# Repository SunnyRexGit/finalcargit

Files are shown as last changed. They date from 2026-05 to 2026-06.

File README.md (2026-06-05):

# ESP32-S3 遥控小车工程

函数说明和调参入口见：[main.cpp 函数说明与调参指南](docs/main_function_guide.md)。

本项目使用 ESP32-S3 作为主控，通过 MC7RE 2.4G 接收机读取遥控器通道，通过 TTL-RS485 控制 6 个闭环步进电机，通过 PCA9685 控制 4 路舵机。项目替代旧安卓 WiFi TCP 控制方式，主控制方式改为遥控器，不依赖安卓 App，也不依赖 WiFi TCP。

当前固件采用 **M.BUS / SBUS 串行输入**：GPIO18 读取接收机信号，串口参数为 `100000, SERIAL_8E2`，默认启用反相读取。SBUS 原始通道值按 `172~1811` 映射到 `1000~2000`，中位为 `1500`。

## 文件结构

```text
.
├── platformio.ini
├── include/
│   └── config.h
├── src/
│   └── main.cpp
└── README.md
```

## 完整接线表

### ESP32-S3 到 TTL-RS485

| ESP32-S3 | TTL-RS485 |
| --- | --- |
| GPIO16 | RX |
| GPIO17 | TX |
| GND | GND |

串口参数固定为 `115200, SERIAL_8N1`。不要把 RS485 改到其他 GPIO。

### ESP32-S3 到 PCA9685

| ESP32-S3 | PCA9685 |
| --- | --- |
| GPIO11 | SDA |
| GPIO12 | SCL |
| 3.3V/5V  | VCC |
| GND | GND |

PCA9685 地址为 `0x40`，PWM 频率为 `50Hz`。不要改成 GPIO21/GPIO22。

### PCA9685 到舵机

| PCA9685 通道 | 逻辑编号 | 功能 |
| --- | --- | --- |
| 0 | S1 | 云台 / 机械臂旋转 |
| 1 | S2 | 夹爪一侧 |
| 2 | S3 | 夹爪另一侧 |
| 3 | S4 | 机械臂前后 |

### RS485 电机编号

| 地址 | 功能 |
| ---- | --- |
| 1 | M1 底盘轮 1 |
| 2 | M2 底盘轮 2 |
| 3 | M3 底盘轮 3 |
| 4 | M4 底盘轮 4 |
| 5 | M5 机械臂升降 |
| 6 | M6 物料盘旋转 |

M1~M4 使用速度模式，M5/M6 使用绝对位置模式。

### MC7RE 到 ESP32-S3

| MC7RE | ESP32-S3 |
| --- | --- |
| M.BUS / SBUS Signal | GPIO18 |
| VCC | 按接收机规格接 5V 或 3.3V |
| GND | GND |

所有模块必须共地。接收机如果输出的不是反相 SBUS，可在 `include/config.h` 中把 `RC_SERIAL_INVERTED` 改为 `0`。

### 激光模块

| 激光模块 | ESP32-S3 |
| --- | --- |
| Signal | GPIO15 |
| VCC | 按模块规格供电 |
| GND | GND |

GPIO15 默认输出高电平，激光常亮；进入 B2 自动工位模式时按 `LASER_BLINK_INTERVAL_MS` 间隔闪烁。

## 遥控器通道说明

| 通道 | 默认索引宏 | 遥控器操作 | 作用 |
| ---- | --- | --- | --- |
| CH1  | `RC_CH1_INDEX 0` | 右摇杆左右 | 底盘横移 / S1 云台 / 自动工位选择 |
| CH2  | `RC_CH2_INDEX 1` | 右摇杆上下 | 底盘前后 / S4 前后 / 自动工位选择 |
| CH3  | `RC_CH3_INDEX 2` | 左摇杆上下 | M5 机械臂升降 |
| CH4  | `RC_CH4_INDEX 3` | 左摇杆左右 | 底盘原地转向 / 夹爪 |
| CH5  | `RC_CH5_INDEX 4` | 两段开关 | 大模式切换 |
| CH6  | `RC_CH6_INDEX 5` | 两段开关或旋钮 | 子模式切换 |

如果实测通道不对应，修改 `include/config.h` 里的 `RC_CHx_INDEX` 宏即可。例如 CH1 和 CH2 反了，就交换 `RC_CH1_INDEX` 与 `RC_CH2_INDEX`。

模式划分：

```text
CH5 < 1500：底盘 / 物料盘模式
CH5 > 1500：机械臂模式

CH6 < 1500：普通子模式
CH6 > 1500：特殊子模式
```

### A1 普通底盘模式

触发条件：`CH5 < 1500 && CH6 < 1500`

| 通道 | 功能 |
| ---- | --- |
| CH1  | 底盘左右横移 `vx` |
| CH2  | 底盘前后移动 `vy` |
| CH4  | 原地转向 `w` |
| CH3  | 为安全默认不参与  |

混控公式：

```cpp
m1 = vy - vx + w;
m2 = -vy + vx + w;
m3 = -vy - vx + w;
m4 = vy + vx + w;
```

固件会把四路输出归一化到 `-100~100`，再映射到 `0~250 RPM`。

底盘速度是线性映射：遥控器返回值离中位越远，速度百分比越大；速度百分比再线性换算成 `0~MAX_SPEED_RPM`。加速度仍由 `ACCEL_WHEEL` 固定控制，不随摇杆变化。

### A2 物料盘模式

触发条件：`CH5 < 1500 && CH6 > 1500`。进入该模式后底盘会停止。

| 遥控器操作 | 功能 |
| --- | --- |
| CH1 左打到底  | M6 左转一步，`motor6Pos -= 900` |
| CH1 右打到底  | M6 右转一步，`motor6Pos += 900` |
| CH2 下拉到底  | M6 回中，`motor6Pos = 1800` |

这些动作都是边沿触发：摇杆打到底只触发一次，必须回中后才能再次触发。

### B1 底盘微调模式

触发条件：`CH5 > 1500 && CH6 < 1500`。该模式用于底盘低速微调，操控方式和普通底盘模式一致，但满摇杆速度被限制到 `FINE_WHEEL_CMD_MAX`。

| 通道 | 功能 |
| ---- | ---- |
| CH1  | 底盘左右横移，低速微调 |
| CH2  | 底盘前后移动，低速微调 |
| CH4  | 底盘原地转向，低速微调 |

B1 不再控制 S1/S4/M5 或夹爪；机械臂动作由 B2 自动工位流程负责。

### B2 自动工位模式

触发条件：`CH5 > 1500 && CH6 > 1500`。进入该模式后底盘停止，手动机械臂控制暂停，M5 不被 CH3 抢控制。

| 遥控器操作 | 自动动作 |
| --- | --- |
| CH1 左打到底  | 去预夹位 State 1 |
| CH2 上推到底  | 去转台位 State 2 |
| CH1 右打到底  | 去预放位 State 3 |
| CH2 下拉到底  | 取消当前自动动作 / 急停 |

自动工位使用 `millis()` 非阻塞状态机。动作运行中不会接受新的工位指令，除非 CH2 下拉到底取消。

## 控制参数说明

主要参数集中在 `include/config.h`：

| 参数 | 当前值 / 含义 |
| ---- | --- |
| `WHEEL_CMD_MAX` | `100`，底盘上层速度范围为 `-100~100` |
| `FINE_WHEEL_CMD_MAX` | `15`，B1 底盘微调模式满摇杆最大速度命令 |
| `MAX_SPEED_RPM` | `250`，轮电机最大转速映射 |
| `MIN_EFFECTIVE_CMD` | `5`，小于该值视为 0 |
| `RC_DEADZONE` | `60`，遥控器摇杆死区 |
| `RC_TIMEOUT_MS` | `300`，超过该时间无有效帧触发失控保护 |
| `M5_PULSE_MIN/MAX` | M5 机械臂升降最小/最大目标脉冲数 |
| `M5_STEP` | `400`，M5 每次连续更新增加或减少的脉冲数 |
| `M6_STEP` | `900`，M6 每次转动增加或减少的脉冲数 |
| `M6_CENTER` | `1800`，M6 回中目标脉冲数 |
| `S1` | 范围 `0~180` |
| `GRIPPER_OPEN_ANGLE` | `90`，夹爪状态为 1 时写入 |
| `GRIPPER_CLOSE_ANGLE` | `150`，夹爪状态为 0 时写入 |
| `S4` | 实际角度范围 `0~180`，代码直接写入该角度 |
| `HIGH_POS` | `500`，所有 S1/S4 旋转前都会先回到该安全高位，低于 1000 脉冲 |
| 预夹位 | 详见 `auto_station/README.md` |
| 转台位 | 详见 `auto_station/README.md` |
| 预放位 | 详见 `auto_station/README.md` |
| `POSITION_SPEED_M5_AUTO` | `800`，B2 自动工位中 M5 的速度参数 |
| `AUTO_M5_MOVE_WAIT_MS` | `4000`，自动工位每次 M5 位置命令后的等待时间 |

方向反了优先改这些宏：

```cpp
#define CHASSIS_X_SIGN 1
#define CHASSIS_Y_SIGN 1
#define CHASSIS_W_SIGN 1
#define M1_SIGN 1
#define M2_SIGN 1
#define M3_SIGN 1
#define M4_SIGN 1
#define M5_DIR_SIGN 1
#define GRIPPER_S3_REVERSED 0
```

## 完整调试流程

### 第 0 步：安全准备

1. 小车架空，四个轮子离地。
2. 机械臂不要装重物。
3. 初次测试时舵机不要带负载。
4. 确认所有 GND 共地。
5. 确认 RS485 A/B 接线。
6. 确认 PCA9685 单独供电能力足够。
7. 打开 PlatformIO 串口监视器，波特率 `115200`。
8. 准备随时断电。

### 第 1 步：编译上传

```bash
pio run
pio run -t upload
pio device monitor -b 115200
```

默认环境是 `esp32-s3-devkitc-1`。如果你的开发板不是这个型号，修改 `platformio.ini` 中的 `board`。

### 第 2 步：遥控器通道测试

先只给 ESP32 和接收机供电，不接电机负载。串口会周期打印：

```text
CH1=...
CH2=...
CH3=...
CH4=...
CH5=...
CH6=...
mode=...
failsafe=...
```

逐个推动摇杆和开关，确认：

```text
CH1：右摇杆左右
CH2：右摇杆上下
CH3：左摇杆上下
CH4：左摇杆左右
CH5：模式开关
CH6：子模式开关
```

如果通道不对，修改 `RC_CHx_INDEX`。如果方向反了，先不要动接线，优先修改方向宏。

### 第 3 步：失控保护测试

1. 打开遥控器，确认通道正常。
2. 关闭遥控器。
3. 串口应该显示 `FAILSAFE TRIGGERED`。
4. M1~M6 应停止，自动工位应取消。
5. 重新打开遥控器。
6. 必须所有摇杆回中后，串口显示 `FAILSAFE CLEARED`，然后才恢复控制。

失控急停命令只在刚进入失控时发送一次，避免 RS485 总线被重复急停命令占满。

### 第 4 步：PCA9685 和舵机测试

1. 只接 PCA9685 和舵机。
2. 不装机械臂负载。
3. CH5 进入机械臂模式，CH6 进入手动模式。
4. 用 CH1 测试 S1。
5. 用 CH4 左/右打到底测试 S2/S3 夹爪状态变量，确认左打到底为闭合 `0`，右打到底为张开 `1`。
6. 用 CH2 测试 S4。
7. 如果 S4 方向反，直接调整 `include/config.h` 中对应的 S4 实际角度，或检查机械安装。
8. 如果夹爪堵转，修改 `GRIPPER_OPEN_ANGLE` / `GRIPPER_CLOSE_ANGLE`。如果 S3 方向相反，改 `GRIPPER_S3_REVERSED`。

### 第 5 步：RS485 单电机测试

1. 先只接一个底盘电机。
2. 测试 M1 正反转。
3. 再测试 M2/M3/M4。
4. 确认地址是否分别是 1/2/3/4。
5. 如果不动，检查电机地址、RS485 A/B、供电、GND。

### 第 6 步：底盘架空测试

1. 四个轮子离地。
2. CH5 进入底盘模式。
3. CH6 进入普通底盘子模式。
4. 测试前后。
5. 测试左右横移。
6. 测试原地转向。
7. 如果整体方向反，修改 `CHASSIS_X_SIGN` / `CHASSIS_Y_SIGN` / `CHASSIS_W_SIGN`。
8. 如果只有一个轮子方向反，修改对应的 `Mx_SIGN`。

### 第 7 步：M5 升降测试

1. 机械臂不要带重物。
2. CH5 进入机械臂模式。
3. CH6 进入手动模式。
4. CH3 上推，M5 应该上升，`motor5Pos` 减小。
5. CH3 下拉，M5 应该下降，`motor5Pos` 增大。
6. 确认 `M5_PULSE_MIN~M5_PULSE_MAX` 脉冲限位生效。
7. 如果方向反，修改 `M5_DIR_SIGN`。

### 第 8 步：M6 物料盘测试

1. CH5 进入底盘模式。
2. CH6 进入物料盘模式。
3. CH1 左打到底，M6 左转一步 `900`。
4. CH1 右打到底，M6 右转一步 `900`。
5. CH2 下拉到底，M6 回中到 `1800`。
6. 确认必须摇杆回中后才能再次触发。

### 第 9 步：机械臂手动测试

1. CH5 进入机械臂模式。
2. CH6 进入手动模式。
3. CH1 控制底盘左右横移，速度应明显低于普通底盘模式。
4. CH2 控制底盘前后移动，速度应明显低于普通底盘模式。
5. CH4 控制底盘原地转向，速度应明显低于普通底盘模式。

### 第 10 步：自动工位测试

1. CH5 进入机械臂模式。
2. CH6 进入自动工位模式。
3. CH1 左打到底 -> 预夹位。
4. CH2 上推到底 -> 转台位。
5. CH1 右打到底 -> 预放位。
6. CH2 下拉到底 -> 取消 / 急停。
7. 观察串口是否按 `AUTO_STEP` 顺序执行。

自动工位现在所有切换都会先让 M5 回到 `HIGH_POS = 500`，等待 `AUTO_M5_MOVE_WAIT_MS`，再旋转 S1/S4，最后移动 M5 到目标位置，避免机械臂主轴旋转时碰撞。如果 B2 反应慢，优先调小 `AUTO_M5_MOVE_WAIT_MS`；如果旋转前 M5 还没完全回高位，就调大它。

夹爪在自动工位中的状态规则：去预夹位 State 1 时，M5 回到 `HIGH_POS` 后夹爪状态设为 `1=张开`；去转台位 State 2 或预放位 State 3 时，自动动作一启动就先把夹爪状态设为 `0=闭合`，再抬升 M5。

### 第 11 步：完整作业流程测试

1. 底盘移动到目标物附近。
2. 进入预夹位。
3. 使用 B1 底盘微调模式对准夹取位置。
4. 夹爪闭合。
5. 转到转台位。
6. M6 物料盘旋转。
7. 底盘移动到放置区。
8. 进入预放位。
9. 夹爪打开。

## 常见问题排查

### 1. 遥控器通道没有变化怎么办

检查接收机是否输出 SBUS/M.BUS，信号线是否接到 GPIO18，遥控器和接收机是否已对频。确认 `RC_SERIAL_INVERTED` 是否符合接收机输出。

### 2. SBUS / M.BUS 没有数据怎么办

先只接 ESP32 和接收机，打开串口监视器。如果始终 failsafe，尝试把 `RC_SERIAL_INVERTED` 改为 `0`，或者确认接收机输出协议不是 PWM 单通道。

### 3. 舵机乱甩怎么办

检查 PCA9685 电源是否独立且电流足够，GND 是否共地。首次测试不要带机械负载，并缩小舵机角度范围。

### 4. S4 方向反了怎么办

S4 现在直接使用实际角度，不再做 `180 - angle` 换算。如果方向不符合预期，检查连杆安装方向，或直接调整自动工位中的 S4 实际角度参数。

### 5. 夹爪堵转怎么办

减小 `GRIPPER_CLOSE_ANGLE` 或增大 `GRIPPER_OPEN_ANGLE` 的安全余量。如果 S3 与 S2 应该反向运动，把 `GRIPPER_S3_REVERSED` 改为 `1`。

### 6. M5 一上电乱跑怎么办

确认 M5 没有在 `setup()` 中清零。本项目只给 M1~M4 清零，M5/M6 保持原有位置记忆。检查驱动器地址、绝对位置模式和机械限位。

### 7. M5 升降方向反了怎么办

修改 `M5_DIR_SIGN`。当前 `motor5Pos` 直接表示 M5 目标脉冲数：CH3 上推时 `motor5Pos -= M5_STEP`，CH3 下拉时 `motor5Pos += M5_STEP`。

### 8. 底盘前后左右方向反了怎么办

修改 `CHASSIS_X_SIGN`、`CHASSIS_Y_SIGN` 或 `CHASSIS_W_SIGN`。如果只是某个轮反了，改对应的 `M1_SIGN` 到 `M4_SIGN`。

### 9. 四个轮子有一个方向不对怎么办

确认电机地址是否正确。如果地址正确，修改对应轮子的 `Mx_SIGN`。

### 10. RS485 电机没响应怎么办

检查电机地址、TTL-RS485 模块供电、A/B 接线、GND 共地、串口波特率。串口会打印电机返回值：`0x02` 表示 OK，`0xE2` 表示参数错误，`0xEE` 表示格式错误。

### 11. 关闭遥控器后电机还在动怎么办

确认接收机在失控时是否输出 SBUS lost frame / failsafe 标志。即使没有标志，固件也会在 `RC_TIMEOUT_MS = 300` 毫秒无有效帧后触发急停。

### 12. PlatformIO 编译库找不到怎么办

检查网络和 PlatformIO 库安装。依赖写在 `platformio.ini`：

```ini
lib_deps =
    adafruit/Adafruit PWM Servo Driver Library
```

### 13. PCA9685 检测不到怎么办

检查 SDA=GPIO11、SCL=GPIO12、地址 `0x40`、VCC、GND。PCA9685 舵机电源和逻辑电源要按模块说明连接，且所有模块共地。

## 继承关系总结

继承自旧 ESP32Robot.ino：

```text
RS485 GPIO16/GPIO17
RS485 115200 SERIAL_8N1
PCA9685 GPIO11/GPIO12
PCA9685 地址 0x40，频率 50Hz
SERVOMIN = 102，SERVOMAX = 512
M1~M6 地址 = 1~6
S1~S4 通道 = 0~3
电机使能、停止、清零、速度、绝对位置命令格式
只给 M1~M4 清零，M5/M6 不清零
```

继承自旧安卓端：

```text
底盘混控逻辑
S1 初始 180，步长 5
S2/S3 打开 90，闭合 150
S4 直接按实际角度写入
M5 现已改为直接脉冲控制，步长 M5_STEP
M6 现已改为直接脉冲控制，步长 M6_STEP，回中 M6_CENTER
HIGH_POS = 500
预夹位、转台位、预放位参数和切换顺序
```

需要实机微调的地方：

```text
SBUS 是否需要反相
RC_CHx_INDEX 通道顺序
底盘方向宏和单轮方向宏
M5_DIR_SIGN
夹爪开合角度和 GRIPPER_S3_REVERSED
自动工位 M5/S1/S4 目标位置
PCA9685 舵机脉宽 SERVOMIN/SERVOMAX
```

第一次上电前必须检查：

```text
小车架空
机械臂无重物
舵机无负载或负载已释放
所有 GND 共地
RS485 A/B、RX/TX 接线正确
PCA9685 供电足够
遥控器可触发 failsafe
随时可以断电
```

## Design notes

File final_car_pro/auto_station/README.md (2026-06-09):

# 自动工位流程梳理

本文按当前代码记录 B2 自动工位流程。所有 S4 角度均为实际写入角度，不再使用逻辑角度换算。

## 自动工位触发

| 遥控动作 | 自动流程 |
| --- | --- |
| CH1 左打到底 | State 1，新预夹位 |
| CH2 上推到底 | State 2，转台连贯宏 |
| CH1 右打到底 | State 3，合并预放宏 |
| CH3 上推超过 `1950` | M5 直接归顶到 `0` |

## 位置目标

| 位置 | M5 脉冲 | S1 实际角度 | S4 实际角度 |
| ---- | --- | --- | --- |
| 新预夹位 | `119860` | `0` | `80` |
| 夹取位 | `139860` | 保持当前 | 保持当前 |
| 转台位 | `76590` | `180` | `170` |
| 转盘预夹位 | `42000` | `180` | `170` |
| 预放位 | `157000` | `0` | `60` |
| M5 顶部 | `0` | 保持当前 | 保持当前 |
| 安全高位 | `500` | 保持当前 | 保持当前 |

## State 1：CH1 左打到底，新预夹位

1. M5 到安全高位 `500`，等待 `3000ms`。
2. S1 到 `0`，S4 到 `80`。
3. 等待 `500ms`。
4. M5 到新预夹位 `119860`，等待 `3000ms`。
5. 完成，当前状态记为 State 1。

## State 2：CH2 上推到底，转台连贯宏

1. M5 到夹取位 `139860`，等待 `2000ms`。
2. 等待 `500ms`。
3. 快速闭合夹爪，S2/S3 直接写 `170`。
4. M5 到安全高位 `500`，等待 `3000ms`。
5. S1 到 `180`，S4 到转台内收角 `170`。
6. 等待 `500ms`。
7. M5 到转台位 `76590`，等待 `2000ms`。
8. 夹爪先半开到 `120`。
9. M5 到顶部 `0`，等待 `3000ms`。
10. 夹爪完全张开到 `60`。
11. M6 转盘步进一次：`motor6Pos + M6_STEP`。
12. 等待 `500ms`。
13. S1 到 `0`，S4 到预放外展角 `60`。
14. 等待 `500ms`。
15. M5 到新预夹位 `119860`，等待 `3000ms`。
16. 完成，当前状态记为 State 1。

## State 3：CH1 右打到底，合并预放宏

1. M5 到顶部 `0`，等待 `3000ms`。
2. 快速确认夹爪张开，S2/S3 直接写 `60`。
3. S4 内收到转盘角 `170`。
4. 等待 `200ms`。
5. S1 到转盘角 `180`。
6. 等待 `1000ms`。
7. M5 去转盘预夹位 `42000`。
8. 等待 `1500ms` 后提前启动夹爪闭合。
9. 快速闭合夹爪，S2/S3 直接写 `170`。
10. 闭合完成后额外等待 `1000ms`。
11. M5 到顶部 `0`，等待 `3000ms`。
12. S1 到预放角 `0`。
13. 等待 `500ms`。
14. M6 转盘反向步进一次：`motor6Pos - M6_STEP`。
15. 等待 `500ms`。
16. S4 外展到预放角 `60`。
17. 等待 `500ms`。
18. M5 到预放位 `157000`，等待 `3000ms`。
19. 完成，当前状态记为 State 3，夹爪保持当前状态。

## 夹爪模式

| 模式 | 行为 |
| ---- | ---- |
| 快速打开 | 直接写 `60` |
| 转台半开 | 直接写 `120` |
| 快速闭合 | 直接写 `170` |

自动流程中，夹爪动作都直接写目标角度，不再分步执行。

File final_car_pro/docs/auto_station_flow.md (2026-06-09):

# 自动工位流程梳理

本文按当前代码记录 B2 自动工位流程。所有 S4 角度均为实际写入角度，不再使用逻辑角度换算。

## 基本角度和等待

| 项目 | 当前值 |
| ---- | --- |
| S4 上电默认实际角度 | `180` |
| S4 实际角度范围 | `0~180` |
| S1 转盘位角度 | `180` |
| S1 预夹/预放角度 | `0` |
| S4 转盘内收角度 | `170` |
| S4 预放外展角度 | `60` |
| 夹爪张开角度 | `60` |
| 夹爪转台半开角度 | `120` |
| 夹爪闭合角度 | `170` |
| 舵机稳定等待 | `500ms` |
| M5 固定到位等待 | `3000ms` |
| State 2 夹取/转台位等待 | `2000ms` |

## 自动工位触发

| 遥控动作 | 自动流程 |
| --- | --- |
| CH1 左打到底 | State 1，新预夹位 |
| CH2 上推到底 | State 2，转台连贯宏 |
| CH1 右打到底 | State 3，合并预放宏 |
| CH3 上推超过 `1950` | M5 直接归顶到 `0` |

## 位置目标

| 位置 | M5 脉冲 | S1 实际角度 | S4 实际角度 |
| ---- | --- | --- | --- |
| 新预夹位 | `119860` | `0` | `80` |
| 夹取位 | `139860` | 保持当前 | 保持当前 |
| 转台位 | `76590` | `180` | `170` |
| 转盘预夹位 | `42000` | `180` | `170` |
| 预放位 | `157000` | `0` | `60` |
| M5 顶部 | `0` | 保持当前 | 保持当前 |
| 安全高位 | `500` | 保持当前 | 保持当前 |

## State 1：CH1 左打到底，新预夹位

1. M5 到安全高位 `500`，等待 `3000ms`。
2. S1 到 `0`，S4 到 `80`。
3. 等待 `500ms`。
4. M5 到新预夹位 `119860`，等待 `3000ms`。
5. 完成，当前状态记为 State 1。

## State 2：CH2 上推到底，转台连贯宏

1. M5 到夹取位 `139860`，等待 `2000ms`。
2. 等待 `500ms`。
3. 快速闭合夹爪，S2/S3 直接写 `170`。
4. M5 到安全高位 `500`，等待 `3000ms`。
5. S1 到 `180`，S4 到转台内收角 `170`。
6. 等待 `500ms`。
7. M5 到转台位 `76590`，等待 `2000ms`。
8. 夹爪先半开到 `120`。
9. M5 到顶部 `0`，等待 `3000ms`。
10. 夹爪完全张开到 `60`。
11. M6 转盘步进一次：`motor6Pos + M6_STEP`。
12. 等待 `500ms`。
13. S1 到 `0`，S4 到预放外展角 `60`。
14. 等待 `500ms`。
15. M5 到新预夹位 `119860`，等待 `3000ms`。
16. 完成，当前状态记为 State 1。

## State 3：CH1 右打到底，合并预放宏

1. M5 到顶部 `0`，等待 `3000ms`。
2. 快速确认夹爪张开，S2/S3 直接写 `60`。
3. S4 内收到转盘角 `170`。
4. 等待 `200ms`。
5. S1 到转盘角 `180`。
6. 等待 `1000ms`。
7. M5 去转盘预夹位 `42000`。
8. 等待 `1500ms` 后提前启动夹爪闭合。
9. 快速闭合夹爪，S2/S3 直接写 `170`。
10. 闭合完成后额外等待 `1000ms`。
11. M5 到顶部 `0`，等待 `3000ms`。
12. S1 到预放角 `0`。
13. 等待 `500ms`。
14. M6 转盘反向步进一次：`motor6Pos - M6_STEP`。
15. 等待 `500ms`。
16. S4 外展到预放角 `60`。
17. 等待 `500ms`。
18. M5 到预放位 `157000`，等待 `3000ms`。
19. 完成，当前状态记为 State 3，夹爪保持当前状态。

## 夹爪模式

| 模式 | 行为 |
| ---- | ---- |
| 快速打开 | 直接写 `60` |
| 转台半开 | 直接写 `120` |
| 快速闭合 | 直接写 `170` |

自动流程中，夹爪动作都直接写目标角度，不再分步执行。

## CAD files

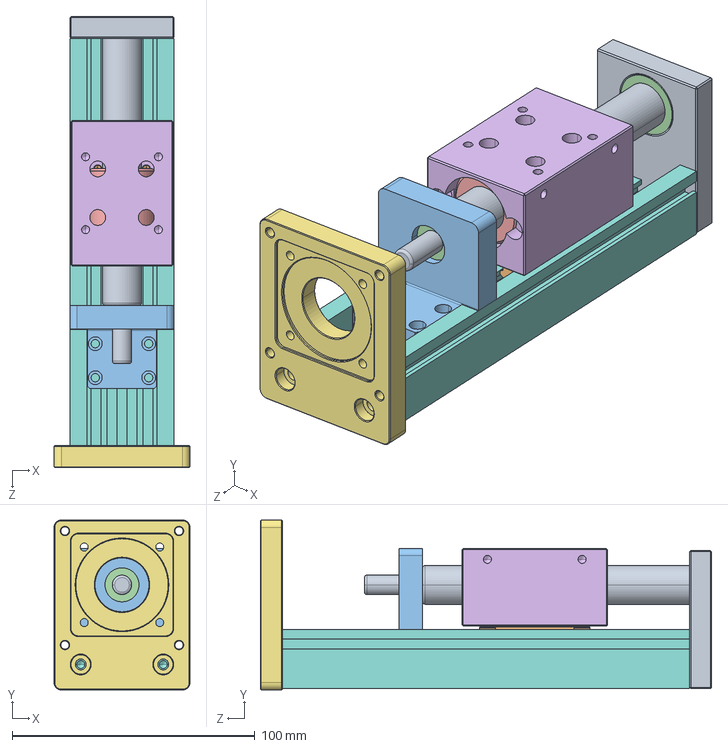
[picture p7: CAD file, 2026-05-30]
final_car_pro/model/标准件/42-57单线..图纸/SGX标准图纸/SGX支撑-50行程.STEP
56.0 x 70.0 x 185.8 mm

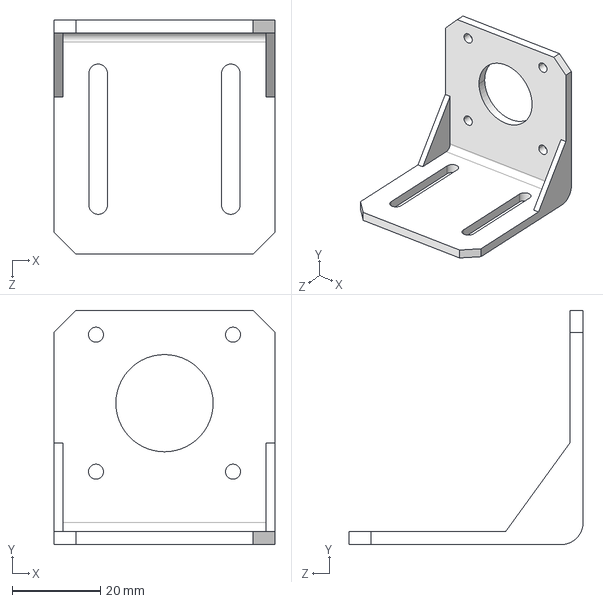
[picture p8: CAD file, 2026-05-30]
final_car_pro/model/标准件/42/42步进电机支架.STEP
50.0 x 53.0 x 53.0 mm

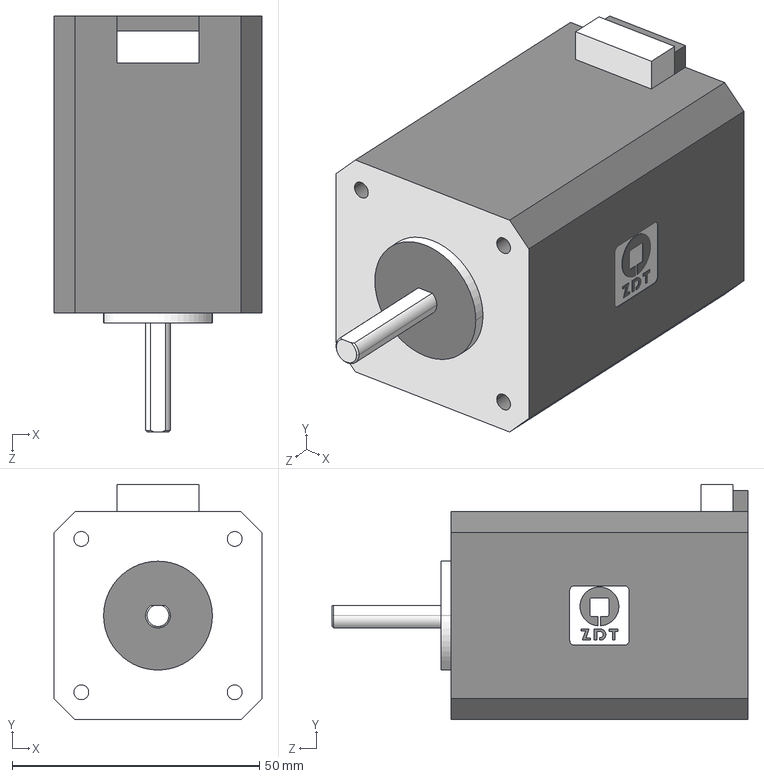
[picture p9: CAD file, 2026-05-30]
final_car_pro/model/标准件/42/单电机/ZDT_STEPPER_MOTOR_42_L60.STEP
42.0 x 47.5 x 84.0 mm

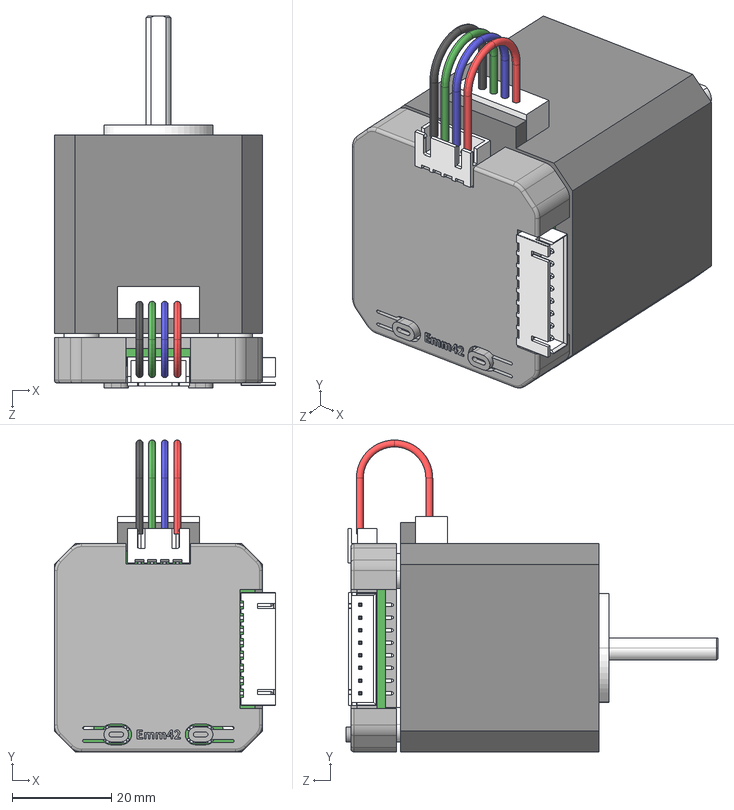
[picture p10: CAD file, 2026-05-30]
final_car_pro/model/标准件/42/电机及驱动外壳/ZDT_X42_L40Motor.STEP
44.7 x 62.9 x 75.0 mm
42_STEPPER_MOTOR
SHIM_3x7x3 x 4
ts-1145a-b-a_White.step x 2
User_Library-XH2_54-4P-AW.step
XH2.54-8P_H-0.step
Extruded.step
Extruded-1.step
M3x6mm_Phillips x 4
ZDT_X42_V1.2
WIRE_2.54

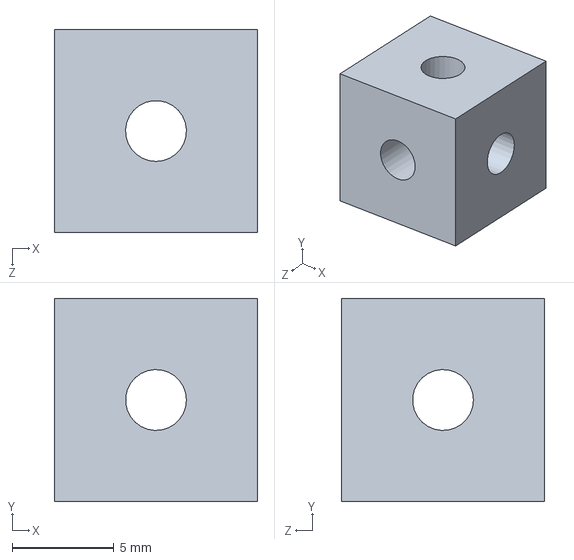
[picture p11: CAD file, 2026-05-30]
final_car_pro/model/标准件/六面螺母.SLDPRT
10.0 x 10.0 x 10.0 mm

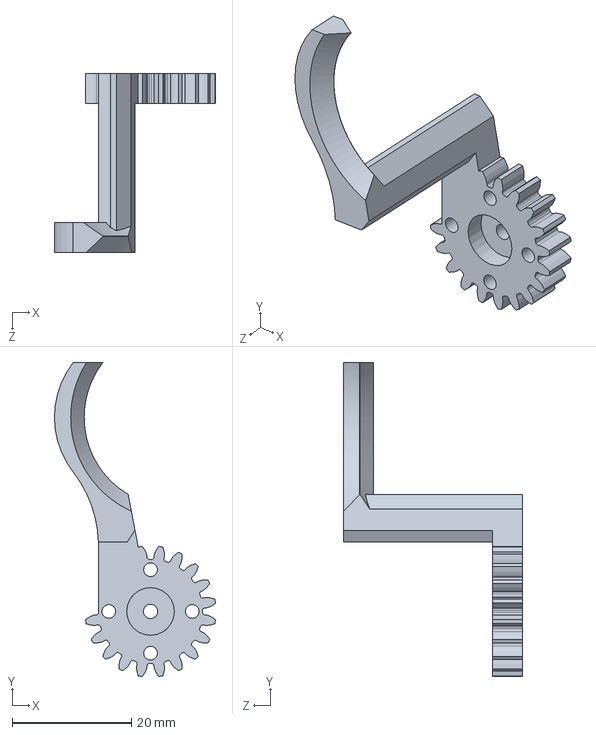
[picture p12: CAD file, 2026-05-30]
final_car_pro/model/零件/夹爪（被动端）.SLDPRT
27.0 x 52.7 x 30.0 mm

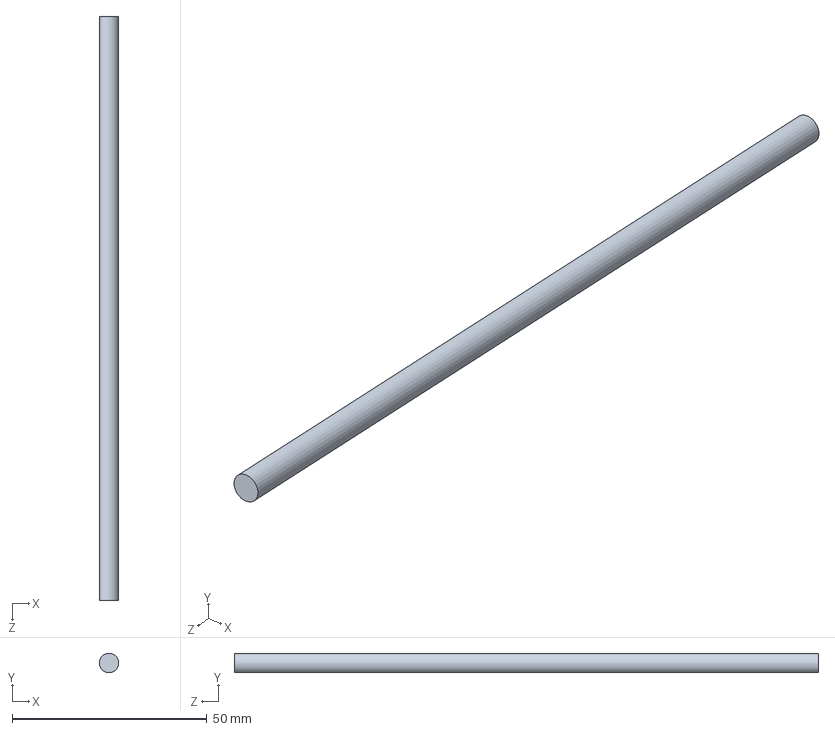
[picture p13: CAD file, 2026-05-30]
final_car_pro/model/标准件/150mm5mm光轴.SLDPRT
5.00 x 4.99 x 150.0 mm

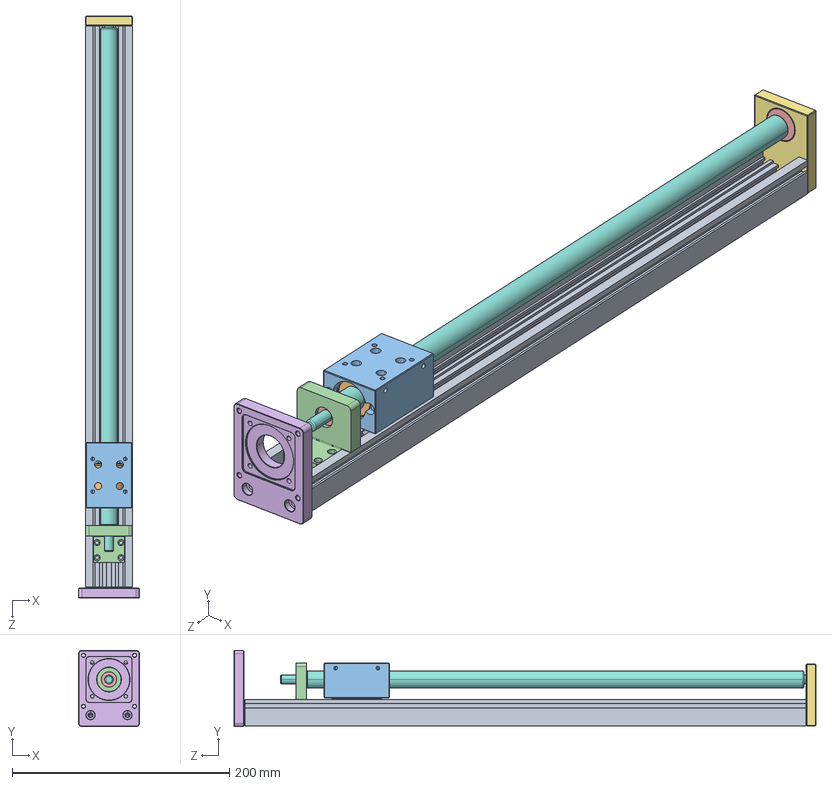
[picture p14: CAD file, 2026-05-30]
final_car_pro/model/标准件/42-57单线..图纸/SGX标准图纸/SGX支撑-400行程.STEP
56.0 x 70.0 x 535.8 mm

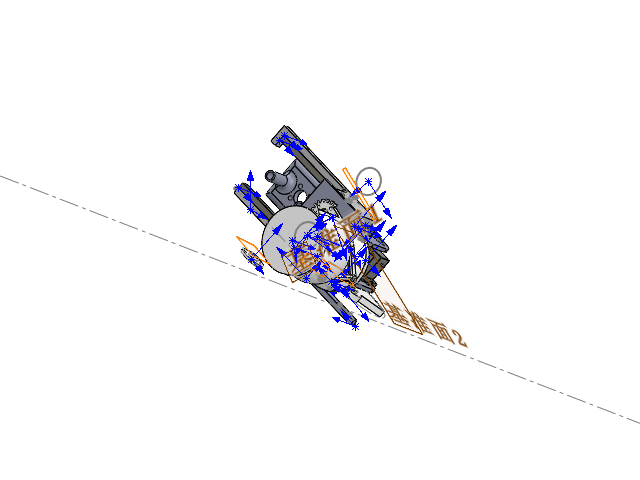
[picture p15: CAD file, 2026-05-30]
final_car_pro/model/装配体/夹爪装配体.SLDASM
100mmMGN7滑轨 x 2
加长MGN7H滑轨块 x 2
（24课11分59秒保存）（答案）MG90S 金属舵机渲染 2018 x 3
（24课11分59秒保存）（答案）cross recessed pan head screws gb(GB_CROSS_SCREWS_TYPE1 M2X4-4 H type-N)2018
凯元齿条L107W30M1
活动夹爪对侧
对侧齿条连接板
夹爪（驱动端）
mg90舵盘 x 3
夹爪抬升机械连接件
夹爪垫片
物料
六面螺母
前限位件
夹爪（被动端）v3
直齿M1X64(修改版)
激光固定件

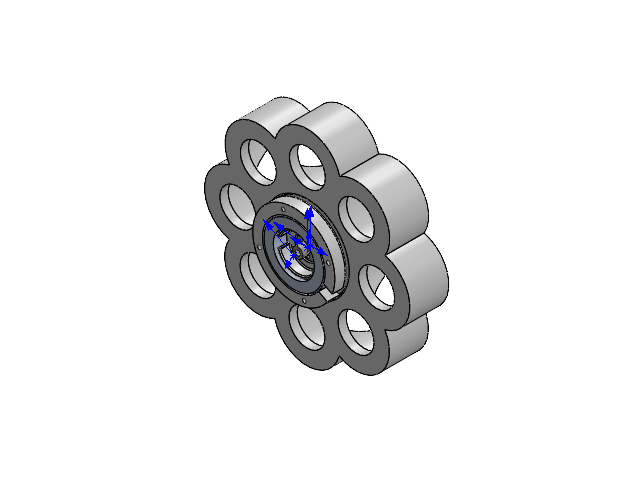
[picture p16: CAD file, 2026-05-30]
final_car_pro/model/装配体/物料盘总装.SLDASM
22_10_5法兰联轴器
40_60_13推力球轴承
物料盘
物料盘轴承固定件

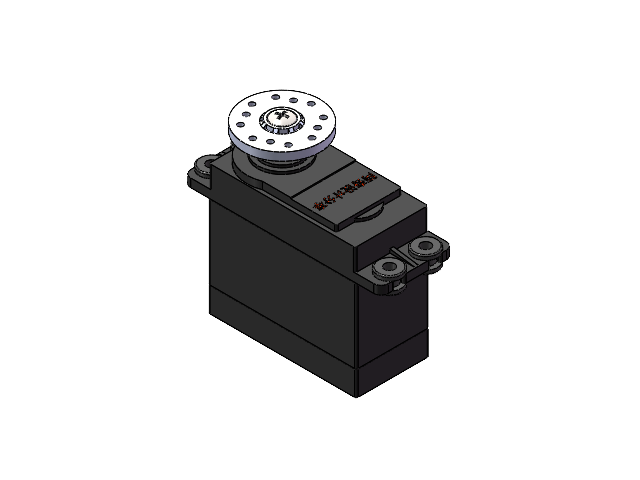
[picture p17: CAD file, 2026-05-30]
final_car_pro/model/装配体/MG996R舵机装配体.SLDASM
（24课11分59秒保存）（答案）大舵机渲染2018
（24课11分59秒保存）（答案）舵机橡胶圈渲染2018 x 4
（24课11分59秒保存）答案）舵机圆舵盘渲染2018
（24课11分59秒保存）（答案）cross recessed pan head screws gb(GB_CROSS_SCREWS_TYPE1 M3X6-6 H type-N)2018

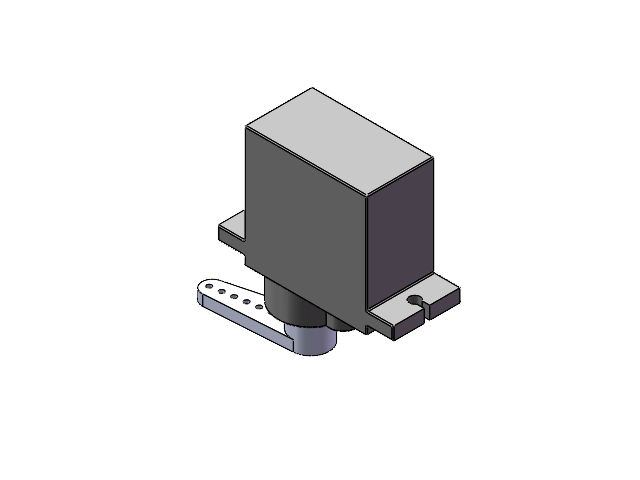
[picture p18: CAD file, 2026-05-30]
final_car_pro/model/标准件/MG90S金属舵机装配体.SLDASM
（24课11分59秒保存）（答案）MG90S 金属舵机渲染 2018
（24课11分59秒保存）（答案）MG90S 金属舵机单舵臂渲染 2018
（24课11分59秒保存）（答案）cross recessed pan head screws gb(GB_CROSS_SCREWS_TYPE1 M2X4-4 H type-N)2018

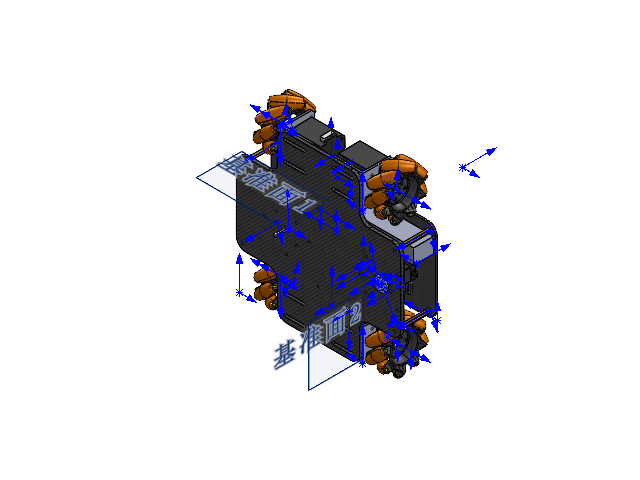
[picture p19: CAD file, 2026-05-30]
final_car_pro/model/装配体/底盘总装.SLDASM
第一层底板
ZDT_STEPPER_MOTOR_42_L48 x 5
3英寸麦轮 x 4
最底层底板
六角螺柱 x 4
42步进电机支架111 x 4
连轴器 x 4
TTL转RS485模块
ESP32S3
1650电池
舵机驱动板
降压模块
（24课11分59秒保存）（答案）大舵机渲染2018
（24课11分59秒保存）（答案）舵机橡胶圈渲染2018 x 4
（24课11分59秒保存）答案）舵机圆舵盘渲染2018
（24课11分59秒保存）（答案）cross recessed pan head screws gb(GB_CROSS_SCREWS_TYPE1 M3X6-6 H type-N)2018
舵机连接第一层底板打印件

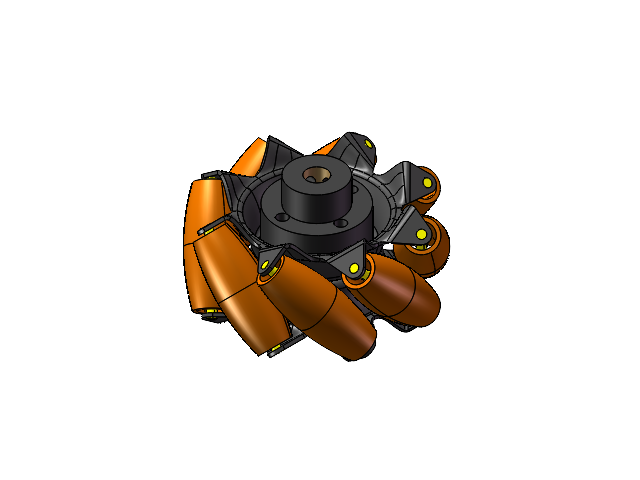
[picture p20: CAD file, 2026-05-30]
final_car_pro/model/标准件/3英寸麦轮联轴器.SLDASM
3英寸麦轮
3英寸麦轮联轴器

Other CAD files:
final_car_pro/model/标准件/MG996R舵机装配体.SLDASM
final_car_pro/model/装配体/机械臂总装.SLDASM
final_car_pro/model/装配体/小车总装.SLDASM
final_car_pro/model/装配体/（24课11分59秒保存）（答案）舵机橡胶圈渲染2018.sldprt
final_car_pro/model/标准件/100mmMGN7滑轨.SLDPRT
final_car_pro/model/标准件/1650电池.SLDPRT
final_car_pro/model/标准件/1650电池.stp
final_car_pro/model/标准件/200mm5mm光轴.SLDPRT
final_car_pro/model/标准件/22_10_5法兰联轴器.SLDPRT
final_car_pro/model/标准件/25物流车测试底盘-底盘-电子-标准件-42闭环步进电机.SLDPRT
final_car_pro/model/标准件/30mm光轴.SLDPRT
final_car_pro/model/标准件/3英寸麦轮(1).stp
final_car_pro/model/标准件/3英寸麦轮.SLDPRT
final_car_pro/model/标准件/40_60_13推力球轴承.SLDPRT
final_car_pro/model/标准件/42-57单线..图纸/SGX标准图纸/SGX-正反牙-单边120.STEP
final_car_pro/model/标准件/42-57单线..图纸/SGX标准图纸/SGX-正反牙.stp
final_car_pro/model/标准件/42-57单线..图纸/SGX标准图纸/SGX-法兰丝杆-57侧装电机板750mm行程(1).stp
final_car_pro/model/标准件/42-57单线..图纸/SGX标准图纸/SGX支撑-1000行程.STEP
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

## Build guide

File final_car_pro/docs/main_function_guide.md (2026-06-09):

# main.cpp 函数说明与调参指南

这份文档专门解释 `src/main.cpp` 里每个函数的目的、调用关系和调参入口。读代码时建议配合 `include/config.h` 一起看：`main.cpp` 负责逻辑，`config.h` 集中放引脚、通道、速度、角度、工位等参数。

## 阅读顺序

1. 先看 `setup()` 和 `loop()`，理解程序启动和主循环。
2. 再看遥控器输入函数，确认 CH1~CH6 是怎样来的。
3. 然后看 RS485 电机函数和 PCA9685 舵机函数，理解底层硬件输出。
4. 最后看四个模式处理函数和自动工位状态机。

## 主要全局变量

### 硬件对象

| 变量 | 作用 | 调参相关 |
| ---- | ---- | --- |
| `MotorSerial(2)` | ESP32-S3 的串口 2，用于 RS485 电机通信 | 引脚在 `RS485_RX_PIN` / `RS485_TX_PIN` |
| `RcSerial(1)` | ESP32-S3 的串口 1，用于读取 MC7RE SBUS/M.BUS | 引脚和反相在 `RC_RX_PIN` / `RC_SERIAL_INVERTED` |
| `pwm` | PCA9685 舵机驱动对象 | 地址在 `PCA9685_ADDRESS` |
| `LASER_PIN` | GPIO15 激光模块控制脚 | 默认常亮；B2 自动工位模式下闪烁 |

### 遥控器状态

| 变量 | 作用 | 注意 |
| ---- | ---- | ---- |
| `rcCh[16]` | 归一化后的遥控器通道，范围 `1000~2000` | 代码主要使用 CH1~CH6 |
| `sbusRaw[16]` | SBUS 原始通道值 | 一般不直接调 |
| `lastRcFrameMs` | 最近一次收到有效 SBUS 帧的时间 | 用于 `RC_TIMEOUT_MS` 失控判断 |
| `rcLostFlag` | SBUS lost frame 标志 | 接收机置位或超时会触发失控 |
| `rcFailsafeFlag` | SBUS failsafe 标志 | 接收机置位会触发失控 |
| `failsafeTriggered` | 本机失控保护锁存标志 | 避免每个 loop 重复发急停 |

### 执行动作状态

| 变量 | 作用 | 调参相关 |
| ---- | ---- | --- |
| `panAngle` | S1 云台当前逻辑角度 | 初值 `SERVO_DEFAULT_S1` |
| `armServoAngle` | S4 当前实际角度 | 代码直接写入该角度 |
| `gripperState` | 夹爪状态变量 | `0=闭合`，`1=张开`，上电默认 `1` |
| `gripperAngle` | S2/S3 夹爪角度 | `GRIPPER_OPEN_ANGLE` / `GRIPPER_CLOSE_ANGLE` |
| `motor5Pos` | M5 当前目标脉冲数 | 范围 `M5_PULSE_MIN~M5_PULSE_MAX`，CH3 按住时每 `M5_UPDATE_MS` 改变一次 `M5_STEP` |
| `motor6Pos` | M6 当前目标脉冲数 | 步长 `M6_STEP`，回中 `M6_CENTER` |
| `lastWheelCmd[4]` | M1~M4 上一次速度命令 | 用于避免重复发送相同速度 |
| `chassisStopped` | 底盘是否已经停止 | 防止模式切换时重复发停止命令 |

### 自动工位状态

| 变量 | 作用 |
| ---- | ---- |
| `autoRunning` | 自动工位是否正在执行 |
| `autoPhase` | 当前自动工位阶段，如到高位、动舵机、到目标位 |
| `currentAutoState` | 当前工位，默认 `2`，即转台位 |
| `targetAutoState` | 目标工位 |
| `autoPhaseStartMs` | 当前阶段开始时间 |
| `autoPhaseDurationMs` | 当前阶段预计等待时间 |
| `autoNeedsFinalMove` | 是否需要先到 `HIGH_POS` 后再到目标 M5 位置 |

## 辅助结构和小函数

### `EdgeLatch`

- 作用：把“摇杆打到底”变成一次性触发，必须回中后才能再次触发。
- 什么时候被调用：物料盘模式和自动工位模式中使用。
- 输入/输出：`low(value)` 检测低端触发，`high(value)` 检测高端触发，返回 `true` 表示刚触发一次。
- 会影响哪些硬件：本身不直接影响硬件，只决定是否允许执行 M6 或自动工位动作。
- 调参相关：`EDGE_LOW_THRESHOLD`、`EDGE_HIGH_THRESHOLD`、`EDGE_CENTER_LOW`、`EDGE_CENTER_HIGH`。
- 注意事项：如果触发太容易，收窄阈值；如果打到底也不触发，放宽阈值。

### `clamp32(int32_t value, int32_t low, int32_t high)`

- 作用：把 32 位整数限制在指定范围内。
- 什么时候被调用：M5/M6 绝对位置命令中。
- 输入/输出：输入原始值、最小值、最大值，返回限位后的值。
- 会影响哪些硬件：间接保护 M5/M6 不越界。
- 调参相关：M5/M6 的最小最大位置常量。
- 注意事项：它只是软件限位，不能替代机械限位和急停。

### `channel(uint8_t indexMacro)`

- 作用：读取 `rcCh[]` 中某个通道的当前归一化值。
- 什么时候被调用：几乎所有模式判断和控制逻辑都会调用。
- 输入/输出：输入通道索引宏，例如 `RC_CH1_INDEX`；返回 `1000~2000`。
- 会影响哪些硬件：本身不影响硬件。
- 调参相关：如果通道对应不对，改 `RC_CH1_INDEX` 到 `RC_CH6_INDEX`。
- 注意事项：这里读的是“索引”，不是 CH 编号本身。

## 程序启动流程

### `setup()`

- 作用：完成整机初始化。
- 什么时候被调用：ESP32 上电或复位后由 Arduino 框架调用一次。
- 输入/输出：无参数，无返回值。
- 会影响哪些硬件：初始化 USB 串口、遥控器串口、PCA9685、RS485 电机，并设置舵机初始角度。
- 调参相关：启动时的舵机角度来自 `SERVO_DEFAULT_S1`、`SERVO_DEFAULT_S4`、`GRIPPER_OPEN_ANGLE`。
- 注意事项：夹爪上电默认状态为 `GRIPPER_STATE_OPEN = 1`，会调用 `setGripperState()` 写入打开角度。

启动顺序：

```text
Serial.begin
rcCh 初始化为 1500
setupRcReceiver
setupPCA9685
setupRS485Motors
设置 S1、S2/S3、S4 初始角度
```

## 主循环流程

### `loop()`

- 作用：主控制循环，负责读取遥控器、处理失控保护、分发四种工作模式。
- 什么时候被调用：Arduino 框架不断循环调用。
- 输入/输出：无参数，无返回值。
- 会影响哪些硬件：间接控制所有电机和舵机。
- 调参相关：模式分界使用 `RC_OUT_MID = 1500`；失控时间使用 `RC_TIMEOUT_MS`。
- 注意事项：自动工位运行时，普通手动模式不会抢控制；只有 CH2 下拉可以取消自动动作。

主流程简化如下：

```text
readRcChannels
如果遥控器无效 -> handleFailsafe -> 返回
如果刚从 failsafe 恢复 -> 必须摇杆回中
updateAutoStateMachine
如果自动工位运行中 -> 只允许取消，不执行手动控制
根据 CH5/CH6 分发到 DRIVE / TRAY / ARM / AUTO
printDebugInfoPeriodically
```

## 遥控器 / SBUS 函数

### `setupRcReceiver()`

- 作用：初始化 MC7RE 接收机串口。
- 什么时候被调用：`setup()` 中。
- 输入/输出：无参数，无返回值。
- 会影响哪些硬件：打开 `RcSerial`，读取 GPIO18 的 SBUS/M.BUS 信号。
- 调参相关：`RC_BAUD_RATE`、`RC_SERIAL_CONFIG`、`RC_RX_PIN`、`RC_TX_PIN`、`RC_SERIAL_INVERTED`。
- 注意事项：如果串口一直没有数据，优先尝试切换 `RC_SERIAL_INVERTED`。

### `readRcChannels()`

- 作用：从串口持续读取 SBUS 字节，组 25 字节帧，解析通道，并判断是否失控。
- 什么时候被调用：每次 `loop()` 一开始。
- 输入/输出：无参数；返回 `true` 表示当前有可用且未失控的遥控器数据。
- 会影响哪些硬件：只读遥控器，不直接控制硬件。
- 调参相关：`RC_TIMEOUT_MS`。
- 注意事项：如果没有新帧，但还没超时，会继续认为信号有效；超时后会触发 failsafe。

### `parseSbusFrame(const uint8_t* frame)`

- 作用：把一帧 SBUS 数据拆成 16 个原始通道，并读取 lost/failsafe 标志。
- 什么时候被调用：`readRcChannels()` 收满 25 字节后。
- 输入/输出：输入 25 字节 SBUS 帧；返回 `true` 表示帧头正确并已解析。
- 会影响哪些硬件：只更新遥控器状态。
- 调参相关：一般不调；如果你的接收机不是标准 SBUS，需要替换这里。
- 注意事项：标准 SBUS 帧头是 `0x0F`，通道位拆包不要随便改。

### `normalizeRcValue(int raw)`

- 作用：把 SBUS 原始值映射到 `1000~2000`。
- 什么时候被调用：`parseSbusFrame()` 中每个通道解析后。
- 输入/输出：输入原始值，返回归一化通道值。
- 会影响哪些硬件：间接影响全部遥控器控制灵敏度。
- 调参相关：`RC_RAW_MIN`、`RC_RAW_MAX`、`RC_OUT_MIN`、`RC_OUT_MAX`。
- 注意事项：如果串口打印的通道最大最小不到 `1000/2000`，可以根据实测修改 raw 范围。

### `channelPercent(int value)`

- 作用：把 `1000~2000` 的摇杆值转换成 `-100~100` 的速度百分比。
- 什么时候被调用：底盘模式中计算 `vx`、`vy`、`w`。
- 输入/输出：输入通道值；返回百分比速度。
- 会影响哪些硬件：间接影响 M1~M4 底盘电机速度。
- 调参相关：`RC_DEADZONE`、`WHEEL_CMD_MAX`。
- 注意事项：死区内返回 0；死区外按遥控器返回值线性映射，越接近 1000/2000，速度百分比越接近 -100/+100。

### `allSticksCentered()`

- 作用：判断 CH1~CH4 摇杆是否都回到中位附近。
- 什么时候被调用：failsafe 恢复逻辑中。
- 输入/输出：无参数；返回 `true` 表示四个摇杆都在死区内。
- 会影响哪些硬件：不直接控制硬件，但决定是否允许恢复控制。
- 调参相关：`RC_DEADZONE`。
- 注意事项：失控恢复后必须回中，这是安全保护，不建议取消。

## PCA9685 / 舵机函数

### `setupPCA9685()`

- 作用：初始化 I2C 和 PCA9685。
- 什么时候被调用：`setup()` 中。
- 输入/输出：无参数，无返回值。
- 会影响哪些硬件：PCA9685 舵机驱动板。
- 调参相关：`PCA9685_SDA_PIN`、`PCA9685_SCL_PIN`、`PCA9685_ADDRESS`、`SERVO_PWM_FREQ`。
- 注意事项：I2C 固定使用 GPIO11/GPIO12，和旧项目一致。

### `setServoRawChannel(int pcaChannel, int angle)`

- 作用：直接向 PCA9685 某个通道写入角度。
- 什么时候被调用：`setServoAngle()` 间接调用。
- 输入/输出：输入 PCA9685 通道和实际角度；无返回值。
- 会影响哪些硬件：对应 PCA9685 通道上的舵机。
- 调参相关：`SERVOMIN`、`SERVOMAX`。
- 注意事项：这是底层函数；平时优先调用 `setServoAngle()`。

### `setServoAngle(uint8_t servoId, int angle)`

- 作用：按 S1~S4 编号设置舵机实际角度。
- 什么时候被调用：启动、手动机械臂、自动工位、夹爪函数中。
- 输入/输出：`servoId` 为 1~4，`angle` 为实际角度；无返回值。
- 会影响哪些硬件：S1~S4 舵机。
- 调参相关：舵机默认角度、自动工位角度。
- 注意事项：S4 不再反向换算，传入多少实际角度就写多少；S2/S3 夹爪建议通过 `setGripperAngle()` 控制。

### `setGripperAngle(int angle)`

- 作用：同时控制 S2 和 S3 夹爪角度。
- 什么时候被调用：`setGripperState()` 中。
- 输入/输出：输入夹爪角度；无返回值。
- 会影响哪些硬件：S2/S3 夹爪舵机。
- 调参相关：`GRIPPER_OPEN_ANGLE`、`GRIPPER_CLOSE_ANGLE`、`GRIPPER_S3_REVERSED`。
- 注意事项：如果夹爪两个舵机需要一正一反，把 `GRIPPER_S3_REVERSED` 改为 `1`。

### `setGripperState(uint8_t state)`

- 作用：按夹爪状态变量控制夹爪，`0=闭合`，`1=张开`。
- 什么时候被调用：上电初始化、B1 手动模式、B2 自动工位启动或回高位后。
- 输入/输出：输入状态值；无返回值。
- 会影响哪些硬件：S2/S3 夹爪舵机。
- 调参相关：`GRIPPER_STATE_CLOSED`、`GRIPPER_STATE_OPEN`、`GRIPPER_CLOSE_ANGLE`、`GRIPPER_OPEN_ANGLE`。
- 注意事项：状态为 1 时写入打开角度，状态为 0 时写入闭合角度；串口会打印 `GRIPPER: state=... angle=...`。

### `updateLaserForMode()`

- 作用：控制 GPIO15 激光输出：默认常亮，B2 自动工位模式下闪烁。
- 什么时候被调用：`loop()` 通过 failsafe 恢复检查后、自动状态机和模式分发前。
- 输入/输出：无参数，无返回值。
- 会影响哪些硬件：GPIO15 上连接的激光模块。
- 调参相关：激光引脚在 `LASER_PIN`；闪烁间隔在 `LASER_BLINK_INTERVAL_MS`；B2 判断阈值使用 `RC_OUT_MID = 1500`。
- 注意事项：非 B2 模式保持高电平常亮；B2 自动工位模式按间隔翻转高低电平形成闪烁。

## RS485 电机函数

### `setupRS485Motors()`

- 作用：初始化 RS485 串口，使能 M1~M6，并给 M1~M4 清零。
- 什么时候被调用：`setup()` 中。
- 输入/输出：无参数，无返回值。
- 会影响哪些硬件：全部 6 个闭环步进电机。
- 调参相关：`RS485_RX_PIN`、`RS485_TX_PIN` 固定为 GPIO16/GPIO17。
- 注意事项：M5/M6 不清零，保留驱动器自己的位置记忆；这是为了避免机械臂一上电乱跑。

### `sendMotorCommand(uint8_t addr, const uint8_t* cmd, size_t len)`

- 作用：RS485 底层发送函数，打印命令，写串口，flush，等待并打印返回值。
- 什么时候被调用：所有电机命令函数都会调用它。
- 输入/输出：输入电机地址、命令数组、命令长度；无返回值。
- 会影响哪些硬件：RS485 总线上的目标电机。
- 调参相关：发送后的短等待是 `delay(20)`，通常不需要改。
- 注意事项：会识别 `0x02` OK、`0xE2` 参数错误、`0xEE` 格式错误。

### `motorEnable(uint8_t idx)`

- 作用：使能指定电机。
- 什么时候被调用：`setupRS485Motors()` 中对 M1~M6 调用。
- 输入/输出：`idx` 是 0 索引，0 对应 M1，5 对应 M6；无返回值。
- 会影响哪些硬件：指定 RS485 电机。
- 调参相关：电机地址数组 `motorAddr[6]`。
- 注意事项：命令格式继承旧项目：`addr F3 AB 01 00 6B`。

### `motorStop(uint8_t idx)`

- 作用：停止指定电机。
- 什么时候被调用：failsafe、取消自动工位、急停、单电机停止时。
- 输入/输出：`idx` 是 0 索引；无返回值。
- 会影响哪些硬件：指定 RS485 电机。
- 调参相关：一般不调。
- 注意事项：命令格式继承旧项目：`addr FE 98 00 6B`。

### `setCurrentAsZero(uint8_t idx)`

- 作用：把指定电机当前位置设为零点。
- 什么时候被调用：`setupRS485Motors()` 中只对 M1~M4 调用。
- 输入/输出：`idx` 是 0 索引；无返回值。
- 会影响哪些硬件：指定 RS485 电机的位置零点。
- 调参相关：一般不调。
- 注意事项：不要轻易给 M5/M6 调用，否则机械臂/物料盘的绝对位置基准会改变。

### `setMotorSpeed(uint8_t idx, int cmdPercent)`

- 作用：控制 M1~M4 底盘轮速度。
- 什么时候被调用：`handleDriveMode()` 和 `stopChassisOnce()`。
- 输入/输出：`idx` 为 0~3；`cmdPercent` 为 `-100~100`；无返回值。
- 会影响哪些硬件：M1~M4 底盘电机。
- 调参相关：`WHEEL_CMD_MAX`、`MAX_SPEED_RPM`、`MIN_EFFECTIVE_CMD`、`ACCEL_WHEEL`、`M1_SIGN~M4_SIGN`。
- 注意事项：如果速度和上一次相同，不会重复发 RS485 命令，减少总线压力。
  当前转速也是线性映射：`abs(cmdPercent) / WHEEL_CMD_MAX * MAX_SPEED_RPM`。

### `setMotorAbsPosition(uint8_t idx, int32_t targetPosition)`

- 作用：控制 M5/M6 到绝对位置。
- 什么时候被调用：M5 手动升降、M6 物料盘、自动工位。
- 输入/输出：`idx=4` 表示 M5，`idx=5` 表示 M6；`targetPosition` 是目标脉冲数；无返回值。
- 会影响哪些硬件：M5 机械臂升降或 M6 物料盘。
- 调参相关：M5 手动速度用 `POSITION_SPEED_M5`，B2 自动速度用 `POSITION_SPEED_M5_AUTO`，M5 加速度用 `ACCEL_MOTOR5`；M6 速度用 `POSITION_SPEED_M6`，加速度用 `ACCEL_MOTOR6`。
- 注意事项：M5/M6 现在都不再做上层逻辑值映射，变量值会直接作为目标脉冲数发送给电机；负数只用于决定方向，实际脉冲数取绝对值。

## 安全保护函数

### `emergencyStopAllMotors()`

- 作用：停止 M1~M6 全部电机，并清空底盘速度缓存。
- 什么时候被调用：刚进入 failsafe 时。
- 输入/输出：无参数，无返回值。
- 会影响哪些硬件：全部 RS485 电机。
- 调参相关：一般不调。
- 注意事项：这个函数会连续发 6 个停止命令，所以只在必要时调用。

### `stopChassisOnce()`

- 作用：只在需要时停止 M1~M4 底盘，避免重复发停止命令。
- 什么时候被调用：进入物料盘、机械臂手动、自动工位模式时。
- 输入/输出：无参数，无返回值。
- 会影响哪些硬件：M1~M4 底盘电机。
- 调参相关：一般不调。
- 注意事项：依赖 `chassisStopped` 判断是否已经停过。

### `handleFailsafe()`

- 作用：处理遥控器丢失后的急停动作。
- 什么时候被调用：`loop()` 发现 `readRcChannels()` 返回 false 时。
- 输入/输出：无参数，无返回值。
- 会影响哪些硬件：停止全部电机，取消自动工位。
- 调参相关：`RC_TIMEOUT_MS`、SBUS lost/failsafe 标志。
- 注意事项：使用 `failsafeTriggered` 锁存，只在刚失控时发一次急停，避免 RS485 总线风暴。

### `handleFailsafeAndRecovery()`

- 作用：处理遥控器信号恢复后的安全解锁。
- 什么时候被调用：`loop()` 中遥控器数据恢复后。
- 输入/输出：返回 `true` 表示允许继续控制；返回 `false` 表示还要等待摇杆回中。
- 会影响哪些硬件：不直接控制硬件。
- 调参相关：`RC_DEADZONE`。
- 注意事项：必须 CH1~CH4 全部回中才会打印 `FAILSAFE CLEARED` 并恢复控制。

## 模式处理函数

### `handleDriveMode()`

- 作用：普通底盘模式，读取 CH1/CH2/CH4，计算 M1~M4 混控速度。
- 什么时候被调用：`CH5 < 1500 && CH6 < 1500`。
- 输入/输出：无参数，无返回值。
- 会影响哪些硬件：M1~M4 底盘电机。
- 调参相关：`CHASSIS_X_SIGN`、`CHASSIS_Y_SIGN`、`CHASSIS_W_SIGN`、`M1_SIGN~M4_SIGN`、`WHEEL_CMD_MAX`。
- 注意事项：输出会自动归一化，保证四个轮子的速度不超过 `-100~100`。

混控公式：

```cpp
m1 = vy - vx + w;
m2 = -vy + vx + w;
m3 = -vy - vx + w;
m4 = vy + vx + w;
```

### `handleTrayMode()`

- 作用：物料盘模式，CH1 左右控制 M6 一步一步转，CH2 下拉回中。
- 什么时候被调用：`CH5 < 1500 && CH6 > 1500`。
- 输入/输出：无参数，无返回值。
- 会影响哪些硬件：M6 物料盘，进入该模式会先停止底盘。
- 调参相关：`M6_STEP`、`M6_CENTER`、边沿触发阈值。
- 注意事项：使用 `EdgeLatch`，必须摇杆回中后才能再次触发一步。

### `handleArmManualMode()`

- 作用：机械臂手动模式，控制 S1、S4、M5 和夹爪。
- 什么时候被调用：`CH5 > 1500 && CH6 < 1500`。
- 输入/输出：无参数，无返回值。
- 会影响哪些硬件：S1、S2/S3 夹爪、S4、M5，并先停止底盘。
- 调参相关：`SERVO_STEP`、`SERVO_UPDATE_MS`、`M5_STEP`、`M5_UPDATE_MS`、夹爪状态和角度。
- 注意事项：CH1 左右控制 S1 云台旋转；CH4 左打到底把 `gripperState` 设为 0 闭合，CH4 右打到底设为 1 张开；CH4 回中或未触发时保持原状态。M5 按 `M5_UPDATE_MS` 连续更新。

### `updateM5ByChannel(int ch3)`

- 作用：根据 CH3 控制 M5 升降，按住 CH3 时按周期连续发送新位置。
- 什么时候被调用：`handleArmManualMode()` 中。
- 输入/输出：输入 CH3 当前值；无返回值。
- 会影响哪些硬件：M5 机械臂升降电机。
- 调参相关：`M5_STEP`、`M5_DIR_SIGN`、`M5_UPDATE_MS`、`EDGE_LOW_THRESHOLD`、`EDGE_HIGH_THRESHOLD`。
- 注意事项：`motor5Pos` 现在直接是目标脉冲数。CH3 上推时目标脉冲数减小；CH3 下拉时目标脉冲数增大。按住不放会每 `M5_UPDATE_MS` 毫秒发送一次。

### `handleArmAutoMode()`

- 作用：自动工位模式，接收工位选择和取消指令。
- 什么时候被调用：`CH5 > 1500 && CH6 > 1500`。
- 输入/输出：无参数，无返回值。
- 会影响哪些硬件：可能启动 M5/S1/S4 自动动作，并先停止底盘。
- 调参相关：自动工位参数和边沿触发阈值。
- 注意事项：自动工位运行中不会接受新的工位选择，只接受 CH2 下拉取消。

## 自动工位函数

### `startAutoState(uint8_t state)`

- 作用：启动一个自动工位切换流程。
- 什么时候被调用：`handleArmAutoMode()` 检测到 CH1/CH2 边沿触发时。
- 输入/输出：输入目标状态 `1/2/3`；无返回值。
- 会影响哪些硬件：立即可能发送 M5 到 `HIGH_POS` 或目标位置的命令。
- 调参相关：`HIGH_POS`、`PRE_CLAMP_*`、`TURNTABLE_*`、`PRE_DROP_*`。
- 注意事项：State 2 会先到夹取位再闭合夹爪，到转台位后半开到 `120`，回顶后再完全张开到 `60`；State 3 会先回顶确认夹爪张开，中途闭合夹爪，移动到预放位后不再自动打开夹爪。

### `cancelAutoMacro(bool stopMotors)`

- 作用：取消自动工位流程。
- 什么时候被调用：failsafe、自动模式 CH2 下拉取消、自动运行中取消。
- 输入/输出：`stopMotors=true` 时会额外停止 M5/M6；无返回值。
- 会影响哪些硬件：可选停止 M5/M6。
- 调参相关：一般不调。
- 注意事项：failsafe 中已经调用全电机急停，所以传 `false`，避免重复停止。

### `updateAutoStateMachine()`

- 作用：推进自动工位非阻塞状态机。
- 什么时候被调用：每次 `loop()` 中，在模式分发之前。
- 输入/输出：无参数，无返回值。
- 会影响哪些硬件：按阶段控制 M5、S1、S4。
- 调参相关：`AUTO_SERVO_SETTLE_MS`、`estimateMotor5MoveTime()`、各工位目标参数。
- 注意事项：它不使用长 `delay()`，而是依靠 `millis()` 判断当前阶段是否完成。

自动流程大致为：

```text
所有自动工位切换：
M5 -> HIGH_POS
S1/S4 -> 目标角度
等待 500ms
M5 -> 目标高度
完成
```

### `estimateMotor5MoveTime(int32_t from, int32_t to)`

- 作用：估算 M5 从当前位置移动到目标位置需要等待多久。
- 什么时候被调用：自动工位启动和阶段切换时。
- 输入/输出：输入起点和终点；返回等待毫秒数。
- 会影响哪些硬件：不直接控制硬件，但影响自动状态机等待时间。
- 调参相关：当前直接返回 `AUTO_M5_MOVE_WAIT_MS`。
- 注意事项：没有读取电机到位反馈时，这个值就是自动流程等待 M5 到位的依据。B2 反应慢就调小；S1/S4 旋转前 M5 还没回到安全高位就调大。

### `getAutoTargets(uint8_t state, int32_t& m5, int& s1, int& s4)`

- 作用：根据工位编号取出 M5、S1、S4 的目标值。
- 什么时候被调用：启动自动工位和推进自动状态机时。
- 输入/输出：输入状态 `1/2/3`；通过引用输出目标 M5/S1/S4。
- 会影响哪些硬件：不直接控制硬件，但决定自动工位最终动作。
- 调参相关：`PRE_CLAMP_MOTOR5`、`PRE_CLAMP_SERVO0`、`PRE_CLAMP_SERVO3`、`TURNTABLE_*`、`PRE_DROP_*`。
- 注意事项：S4 输出的是实际角度，不再做 `180 - angle` 换算。

### `transitionUsesHighPos(uint8_t fromState, uint8_t toState)`

- 作用：判断某次工位切换是否需要先经过安全高位 `HIGH_POS`。
- 什么时候被调用：`startAutoState()` 中。
- 输入/输出：输入当前工位和目标工位；返回是否需要先升到高位。
- 会影响哪些硬件：间接决定 M5 的运动路径。
- 调参相关：当前固定返回 `true`，也就是所有自动切换都会先回 `HIGH_POS`。
- 注意事项：这样可以保证旋转 S1/S4 前，M5 已经回到 1000 脉冲以内的安全高度，减少碰撞风险。

## 调试输出函数

### `printDebugInfoPeriodically()`

- 作用：周期打印遥控器通道、模式、failsafe、自动工位、电机和舵机状态。
- 什么时候被调用：`loop()` 多个分支末尾都会调用。
- 输入/输出：无参数，无返回值。
- 会影响哪些硬件：不影响硬件，只打印串口。
- 调参相关：`DEBUG_PRINT_MS`。
- 注意事项：如果串口刷屏太快，增大 `DEBUG_PRINT_MS`；如果想更实时，减小它。

输出格式类似：

```text
CH1=1500 CH2=1500 CH3=1500 CH4=1500 CH5=1000 CH6=1000 mode=DRIVE failsafe=0 auto=0 M1=0 M2=0 M3=0 M4=0 M5=0 M6=0 S1=180 S4=0 gripState=1 gripAngle=90
```

## 调参速查表

| 现象 | 优先修改 |
| ---- | --- |
| 遥控器通道对应不对 | `RC_CH1_INDEX` 到 `RC_CH6_INDEX` |
| 摇杆中位有小幅抖动 | 增大 `RC_DEADZONE` |
| 摇杆需要推很多才有反应 | 减小 `RC_DEADZONE` |
| 底盘前后方向反 | `CHASSIS_Y_SIGN` |
| 底盘左右横移方向反 | `CHASSIS_X_SIGN` |
| 原地转向方向反 | `CHASSIS_W_SIGN` |
| 单个轮子方向反 | `M1_SIGN` 到 `M4_SIGN` |
| 底盘太快 | 降低 `MAX_SPEED_RPM` 或 `WHEEL_CMD_MAX` |
| 底盘起步太敏感 | 增大 `MIN_EFFECTIVE_CMD` |
| M5 升降方向反 | `M5_DIR_SIGN` |
| M5 行程不对 | `M5_PULSE_MIN/MAX` |
| M5 每次动太多 | 减小 `M5_STEP` |
| M5 按住升降太快 | 减小 `M5_STEP` 或增大 `M5_UPDATE_MS` |
| M6 每步转动脉冲不合适 | 修改 `M6_STEP` |
| M6 回中脉冲位置不对 | 修改 `M6_CENTER` |
| 夹爪打不开或夹不紧 | `GRIPPER_OPEN_ANGLE` / `GRIPPER_CLOSE_ANGLE` |
| 夹爪两个舵机方向不匹配 | `GRIPPER_S3_REVERSED` |
| S4 方向看起来不对 | 先确认机械安装，再直接调整 S4 实际角度参数 |
| 自动工位高度不对 | `PRE_CLAMP_MOTOR5`、`TURNTABLE_MOTOR5`、`PRE_DROP_MOTOR5` |
| 自动工位 M5 太快 | 减小 `POSITION_SPEED_M5_AUTO` |
| 自动工位角度不对 | `PRE_CLAMP_SERVO0/SERVO3`、`TURNTABLE_SERVO0/SERVO3`、`PRE_DROP_SERVO0/SERVO3` |
| 自动工位等待太短 | 调整 `estimateMotor5MoveTime()` 或增大 `AUTO_SERVO_SETTLE_MS` |
| 关闭遥控器后急停太慢 | 减小 `RC_TIMEOUT_MS` |
| 遥控器偶发误触发 failsafe | 增大 `RC_TIMEOUT_MS`，检查接收机供电和 SBUS 线 |

## 实机调参建议顺序

1. 只接 ESP32 和接收机，确认 CH1~CH6 打印正确。
2. 只接 PCA9685 和舵机，调 S1/S2/S3/S4 的角度和方向。
3. 只接一个底盘电机，确认 RS485 地址和方向。
4. 架空底盘，调四轮方向宏和速度。
5. 单独测试 M5 升降，确认方向、行程和限位。
6. 单独测试 M6 物料盘，确认步长和回中。
7. 最后再测试自动工位，微调三个工位参数。

## 改代码时最容易踩的点

- `idx` 是 0 索引：`idx=0` 是 M1，`idx=4` 是 M5，`idx=5` 是 M6。
- `servoId` 是 1 索引：`servoId=1` 是 S1，`servoId=4` 是 S4。
- S4 的 `angle` 是实际角度，写入 PCA9685 前不再反向换算。
- M5 的 `motor5Pos` 现在就是目标脉冲数，不再经过另一套位置单位换算。
- M6 的 `motor6Pos` 现在也是目标脉冲数，支持正负方向，方向由 `pos >= 0` 判断。
- `setMotorSpeed()` 有缓存，相同速度不会重复发命令。
- failsafe 恢复后必须所有摇杆回中，否则 `loop()` 不会进入正常控制。
- 自动工位运行时手动控制会暂停，防止 M5/S1/S4 被抢控制。

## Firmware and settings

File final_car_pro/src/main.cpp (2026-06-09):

#include <Arduino.h>
#include <Wire.h>
#include <Adafruit_PWMServoDriver.h>

#include "config.h"

HardwareSerial MotorSerial(2);
HardwareSerial RcSerial(1);
Adafruit_PWMServoDriver pwm(PCA9685_ADDRESS);

const uint8_t motorAddr[6] = {1, 2, 3, 4, 5, 6};
const int SERVO_CH[4] = {0, 1, 2, 3};
constexpr uint8_t AUTO_STATE_CH2_LOW = 4;

int rcCh[16] = {1500};
uint16_t sbusRaw[16] = {0};
uint8_t sbusFrame[25] = {0};
uint8_t sbusFramePos = 0;
uint32_t lastRcFrameMs = 0;
bool rcLostFlag = true;
bool rcFailsafeFlag = true;
bool failsafeTriggered = false;
bool rcWasOk = false;

int panAngle = SERVO_DEFAULT_S1;
int armServoAngle = SERVO_DEFAULT_S4;
uint8_t gripperState = GRIPPER_STATE_OPEN;
int gripperAngle = GRIPPER_OPEN_ANGLE;
int gripperTargetAngle = GRIPPER_OPEN_ANGLE;
int32_t motor5Pos = M5_PULSE_MIN;
int32_t motor6Pos = 0;

int lastWheelCmd[4] = {0, 0, 0, 0};
bool chassisStopped = false;
uint32_t lastDebugPrintMs = 0;
uint32_t lastLaserBlinkMs = 0;
uint32_t laserRcConnectBlinkStartMs = 0;
bool laserBlinkState = true;
bool laserRcConnectBlinkActive = false;

struct EdgeLatch {
  bool lowArmed = true;
  bool highArmed = true;

  bool low(int value) {
    updateCenter(value);
    if (lowArmed && value < EDGE_LOW_THRESHOLD) {
      lowArmed = false;
      return true;
    }
    return false;
  }

  bool high(int value, int threshold = EDGE_HIGH_THRESHOLD) {
    updateCenter(value);
    if (highArmed && value > threshold) {
      highArmed = false;
      return true;
    }
    return false;
  }

  void updateCenter(int value) {
    if (value > EDGE_CENTER_LOW && value < EDGE_CENTER_HIGH) {
      lowArmed = true;
      highArmed = true;
    }
  }
};

EdgeLatch trayCh1Edge;
EdgeLatch trayCh2Edge;
EdgeLatch gripperCh4Edge;
EdgeLatch autoCh1Edge;
EdgeLatch autoCh2Edge;
EdgeLatch autoCh3Edge;

enum class AutoPhase {
  Idle,
  MoveHigh,
  MoveTarget,
  WaitServoSettle,
  Done,
  TurntableMovePickup,
  TurntableWaitBeforeClose,
  TurntableWaitGripperClose,
  TurntableMoveHigh,
  TurntableWaitServoSettle,
  TurntableMoveToTarget,
  TurntableWaitGripperOpen,
  TurntableMoveTopAfterOpen,
  TurntableStepTray,
  TurntableRotatePreClamp,
  TurntableMovePreClamp,
  TurntableFinishPreClamp,
  PreDropMoveTopForOpen,
  PreDropWaitGripperOpen,
  PreDropSetS4ToTurntable,
  PreDropSetS1ToTurntable,
  PreDropMoveToTurntableClamp,
  PreDropWaitGripperClose,
  PreDropWaitAfterClose,
  PreDropMoveTopAfterClamp,
  PreDropSetS1ToDrop,
  PreDropReverseTray,
  PreDropSetS4ToDrop,
  PreDropMoveToDrop,
};

bool autoRunning = false;
AutoPhase autoPhase = AutoPhase::Idle;
uint8_t currentAutoState = 2;
uint8_t targetAutoState = 2;
uint32_t autoPhaseStartMs = 0;
uint32_t autoPhaseDurationMs = 0;
bool autoNeedsFinalMove = false;
int32_t autoStartM5 = 0;
int32_t autoIntermediateM5 = HIGH_POS;
int32_t autoTargetM5 = TURNTABLE_MOTOR5;

int32_t clamp32(int32_t value, int32_t low, int32_t high) {
  if (value < low) return low;
  if (value > high) return high;
  return value;
}

int channel(uint8_t indexMacro) {
  return rcCh[indexMacro];
}

void setupRcReceiver();
bool readRcChannels();
bool parseSbusFrame(const uint8_t* frame);
int normalizeRcValue(int raw);
int channelPercent(int value);
int channelPercentWithMax(int value, int maxCmd);
bool allSticksCentered();

void setupPCA9685();
void setupRS485Motors();
void sendMotorCommand(uint8_t addr, const uint8_t* cmd, size_t len);
void motorEnable(uint8_t idx);
void motorStop(uint8_t idx);
void setCurrentAsZero(uint8_t idx);
void setMotorSpeed(uint8_t idx, int cmdPercent);
void setMotorAbsPosition(uint8_t idx, int32_t targetPosition, uint16_t speedOverride = 0);
void emergencyStopAllMotors();
void stopChassisOnce();

void setServoRawChannel(int pcaChannel, int angle);
void setServoAngle(uint8_t servoId, int angle);
void setGripperAngle(int angle);
void setGripperState(uint8_t state);
void setGripperStateFast(uint8_t state);
void setGripperReleaseAngleFast(int angle);

void updateLaserForMode();
void startLaserRcConnectBlink();
void handleFailsafe();
bool handleFailsafeAndRecovery();
void handleDriveMode();
void handleTrayMode();
void handleChassisFineMode();
void handleArmAutoMode();
void handleGripperByChannel(int ch4);
void startAutoState(uint8_t state);
void cancelAutoMacro(bool stopMotors);
void updateAutoStateMachine();
uint32_t estimateMotor5MoveTime(int32_t from, int32_t to);
void getAutoTargets(uint8_t state, int32_t& m5, int& s1, int& s4);
bool transitionUsesHighPos(uint8_t fromState, uint8_t toState);
void printDebugInfoPeriodically();

void setup() {
  Serial.begin(115200);
  delay(200);
  for (uint8_t i = 0; i < 16; i++) {
    rcCh[i] = RC_OUT_MID;
  }
  Serial.println();
  Serial.println("ESP32-S3 RC car controller starting...");

  pinMode(LASER_PIN, OUTPUT);
  digitalWrite(LASER_PIN, HIGH);

  setupRcReceiver();
  setupPCA9685();
  setupRS485Motors();

  setServoAngle(1, panAngle);
  setGripperStateFast(gripperState);
  setServoAngle(4, armServoAngle);

  Serial.println("Ready. Waiting for valid SBUS/M.BUS receiver frames.");
}

void loop() {
  const bool rcOk = readRcChannels();

  if (rcOk && !rcWasOk) {
    startLaserRcConnectBlink();
  }
  rcWasOk = rcOk;

  if (!rcOk) {
    handleFailsafe();
    printDebugInfoPeriodically();
    return;
  }

  if (!handleFailsafeAndRecovery()) {
    updateLaserForMode();
    printDebugInfoPeriodically();
    return;
  }

  updateLaserForMode();
  updateAutoStateMachine();

  if (channel(RC_CH5_INDEX) < RC_OUT_MID) {
    if (channel(RC_CH6_INDEX) < RC_OUT_MID) {
      handleDriveMode();
    } else {
      handleTrayMode();
    }
  } else {
    if (channel(RC_CH6_INDEX) < RC_OUT_MID) {
      handleChassisFineMode();
    } else {
      stopChassisOnce();
      handleArmAutoMode();
    }
  }

  printDebugInfoPeriodically();
}

void setupRcReceiver() {
  RcSerial.begin(RC_BAUD_RATE, RC_SERIAL_CONFIG, RC_RX_PIN, RC_TX_PIN, RC_SERIAL_INVERTED);
  Serial.printf("RC receiver: SBUS/M.BUS on RX GPIO%d, %d baud, inverted=%d\n",
                RC_RX_PIN, RC_BAUD_RATE, RC_SERIAL_INVERTED);
}

bool readRcChannels() {
  bool frameUpdated = false;

  while (RcSerial.available()) {
    uint8_t b = RcSerial.read();

    if (sbusFramePos == 0 && b != 0x0F) {
      continue;
    }

    sbusFrame[sbusFramePos++] = b;
    if (sbusFramePos >= sizeof(sbusFrame)) {
      sbusFramePos = 0;
      if (parseSbusFrame(sbusFrame)) {
        frameUpdated = true;
        lastRcFrameMs = millis();
      }
    }
  }

  const bool timedOut = (millis() - lastRcFrameMs) > RC_TIMEOUT_MS;
  rcLostFlag = timedOut || rcLostFlag;
  return frameUpdated ? (!rcLostFlag && !rcFailsafeFlag) : (!timedOut && !rcLostFlag && !rcFailsafeFlag);
}

bool parseSbusFrame(const uint8_t* frame) {
  if (frame[0] != 0x0F) return false;

  sbusRaw[0]  = ((frame[1]     | frame[2] << 8) & 0x07FF);
  sbusRaw[1]  = ((frame[2] >> 3 | frame[3] << 5) & 0x07FF);
  sbusRaw[2]  = ((frame[3] >> 6 | frame[4] << 2 | frame[5] << 10) & 0x07FF);
  sbusRaw[3]  = ((frame[5] >> 1 | frame[6] << 7) & 0x07FF);
  sbusRaw[4]  = ((frame[6] >> 4 | frame[7] << 4) & 0x07FF);
  sbusRaw[5]  = ((frame[7] >> 7 | frame[8] << 1 | frame[9] << 9) & 0x07FF);
  sbusRaw[6]  = ((frame[9] >> 2 | frame[10] << 6) & 0x07FF);
  sbusRaw[7]  = ((frame[10] >> 5 | frame[11] << 3) & 0x07FF);
  sbusRaw[8]  = ((frame[12]    | frame[13] << 8) & 0x07FF);
  sbusRaw[9]  = ((frame[13] >> 3 | frame[14] << 5) & 0x07FF);
  sbusRaw[10] = ((frame[14] >> 6 | frame[15] << 2 | frame[16] << 10) & 0x07FF);
  sbusRaw[11] = ((frame[16] >> 1 | frame[17] << 7) & 0x07FF);
  sbusRaw[12] = ((frame[17] >> 4 | frame[18] << 4) & 0x07FF);
  sbusRaw[13] = ((frame[18] >> 7 | frame[19] << 1 | frame[20] << 9) & 0x07FF);
  sbusRaw[14] = ((frame[20] >> 2 | frame[21] << 6) & 0x07FF);
  sbusRaw[15] = ((frame[21] >> 5 | frame[22] << 3) & 0x07FF);

  rcLostFlag = (frame[23] & 0x04) != 0;
  rcFailsafeFlag = (frame[23] & 0x08) != 0;

  for (uint8_t i = 0; i < 16; i++) {
    rcCh[i] = normalizeRcValue(sbusRaw[i]);
  }

  return true;
}

int normalizeRcValue(int raw) {
  long value = map(raw, RC_RAW_MIN, RC_RAW_MAX, RC_OUT_MIN, RC_OUT_MAX);
  return constrain(value, RC_OUT_MIN, RC_OUT_MAX);
}

int channelPercent(int value) {
  return channelPercentWithMax(value, WHEEL_CMD_MAX);
}

int channelPercentWithMax(int value, int maxCmd) {
  maxCmd = constrain(maxCmd, 0, WHEEL_CMD_MAX);
  value = constrain(value, RC_OUT_MIN, RC_OUT_MAX);
  const int delta = value - RC_OUT_MID;
  if (abs(delta) <= RC_DEADZONE) return 0;

  if (delta > 0) {
    const int activeRange = RC_OUT_MAX - (RC_OUT_MID + RC_DEADZONE);
    const int activeValue = value - (RC_OUT_MID + RC_DEADZONE);
    return constrain((int)((long)activeValue * maxCmd / activeRange), 0, maxCmd);
  }

  const int activeRange = (RC_OUT_MID - RC_DEADZONE) - RC_OUT_MIN;
  const int activeValue = (RC_OUT_MID - RC_DEADZONE) - value;
  return -constrain((int)((long)activeValue * maxCmd / activeRange), 0, maxCmd);
}

bool allSticksCentered() {
  return abs(channel(RC_CH1_INDEX) - RC_OUT_MID) <= RC_DEADZONE &&
         abs(channel(RC_CH2_INDEX) - RC_OUT_MID) <= RC_DEADZONE &&
         abs(channel(RC_CH3_INDEX) - RC_OUT_MID) <= RC_DEADZONE &&
         abs(channel(RC_CH4_INDEX) - RC_OUT_MID) <= RC_DEADZONE;
}

void setupPCA9685() {
  Wire.begin(PCA9685_SDA_PIN, PCA9685_SCL_PIN);
  pwm.begin();
  pwm.setPWMFreq(SERVO_PWM_FREQ);
  delay(10);
  Serial.printf("PCA9685: SDA GPIO%d, SCL GPIO%d, address 0x%02X, %u Hz\n",
                PCA9685_SDA_PIN, PCA9685_SCL_PIN, PCA9685_ADDRESS, SERVO_PWM_FREQ);
}

void setupRS485Motors() {
  MotorSerial.begin(115200, SERIAL_8N1, RS485_RX_PIN, RS485_TX_PIN);
  Serial.printf("RS485 motors: RX GPIO%d, TX GPIO%d, 115200 SERIAL_8N1\n",
                RS485_RX_PIN, RS485_TX_PIN);

  for (uint8_t i = 0; i < 6; i++) {
    motorEnable(i);
    delay(50);
    if (i < 4) {
      setCurrentAsZero(i);
    }
    delay(50);
  }
}

void sendMotorCommand(uint8_t addr, const uint8_t* cmd, size_t len) {
  Serial.printf("RS485 TX addr=%u:", addr);
  for (size_t i = 0; i < len; i++) {
    Serial.printf(" %02X", cmd[i]);
  }
  Serial.println();

  MotorSerial.write(cmd, len);
  MotorSerial.flush();
  delay(20);

  while (MotorSerial.available()) {
    uint8_t resp = MotorSerial.read();
    Serial.printf("Resp: %02X", resp);
    if (resp == 0xE2) Serial.println(" -> Parameter error");
    else if (resp == 0xEE) Serial.println(" -> Format error");
    else if (resp == 0x02) Serial.println(" -> OK");
    else Serial.println();
  }
}

void motorEnable(uint8_t idx) {
  if (idx >= 6) return;
  uint8_t cmd[] = {motorAddr[idx], 0xF3, 0xAB, 0x01, 0x00, 0x6B};
  sendMotorCommand(motorAddr[idx], cmd, sizeof(cmd));
}

void motorStop(uint8_t idx) {
  if (idx >= 6) return;
  uint8_t cmd[] = {motorAddr[idx], 0xFE, 0x98, 0x00, 0x6B};
  sendMotorCommand(motorAddr[idx], cmd, sizeof(cmd));
}

void setCurrentAsZero(uint8_t idx) {
  if (idx >= 6) return;
  uint8_t cmd[] = {motorAddr[idx], 0x0A, 0x6D, 0x6B};
  sendMotorCommand(motorAddr[idx], cmd, sizeof(cmd));
}

void setMotorSpeed(uint8_t idx, int cmdPercent) {
  if (idx >= 4) return;

  cmdPercent = constrain(cmdPercent, -WHEEL_CMD_MAX, WHEEL_CMD_MAX);
  if (abs(cmdPercent) < MIN_EFFECTIVE_CMD) cmdPercent = 0;

  if (lastWheelCmd[idx] == cmdPercent) return;
  lastWheelCmd[idx] = cmdPercent;
  chassisStopped = (lastWheelCmd[0] == 0 && lastWheelCmd[1] == 0 &&
                    lastWheelCmd[2] == 0 && lastWheelCmd[3] == 0);

  uint8_t direction = (cmdPercent > 0) ? 0x01 : 0x00;
  uint16_t speedVal = (uint16_t)((uint32_t)abs(cmdPercent) * CHASSIS_MAX_SPEED_RPM_LIMIT / WHEEL_CMD_MAX);
  if (cmdPercent == 0) speedVal = 0;

  uint8_t cmd[] = {
      motorAddr[idx], 0xF6, direction,
      (uint8_t)(speedVal >> 8), (uint8_t)(speedVal & 0xFF),
      CHASSIS_ACCEL_WHEEL_LIMIT, 0x00, 0x6B
  };
  sendMotorCommand(motorAddr[idx], cmd, sizeof(cmd));
}

void setMotorAbsPosition(uint8_t idx, int32_t targetPosition, uint16_t speedOverride) {
  if (idx != 4 && idx != 5) return;

  int32_t pos = targetPosition;
  uint8_t acc = (idx == 4) ? ACCEL_MOTOR5 : ACCEL_MOTOR6;
  uint16_t speed = speedOverride > 0 ? speedOverride : ((idx == 4) ? POSITION_SPEED_M5 : POSITION_SPEED_M6);
  uint32_t pulse = 0;

  if (idx == 4) {
    pos = clamp32(pos, M5_PULSE_MIN, M5_PULSE_MAX);
    motor5Pos = pos;
    pulse = (uint32_t)abs(pos);
  } else {
    pos = clamp32(pos, M6_MIN, M6_MAX);
    motor6Pos = pos;
    pulse = (uint32_t)abs(pos);
  }

  uint8_t direction = (pos >= 0) ? 0x01 : 0x00;
  uint8_t cmd[] = {
      motorAddr[idx], 0xFD, direction,
      (uint8_t)(speed >> 8), (uint8_t)(speed & 0xFF),
      acc,
      (uint8_t)(pulse >> 24), (uint8_t)(pulse >> 16),
      (uint8_t)(pulse >> 8), (uint8_t)(pulse & 0xFF),
      POSITION_MODE_ABSOLUTE, POSITION_SYNC_DISABLED, 0x6B
  };
  sendMotorCommand(motorAddr[idx], cmd, sizeof(cmd));
}

void emergencyStopAllMotors() {
  for (uint8_t i = 0; i < 6; i++) {
    motorStop(i);
    if (i < 4) lastWheelCmd[i] = 0;
  }
  chassisStopped = true;
}

void stopChassisOnce() {
  if (chassisStopped) return;
  for (uint8_t i = 0; i < 4; i++) {
    setMotorSpeed(i, 0);
  }
  chassisStopped = true;
}

void setServoRawChannel(int pcaChannel, int angle) {
  angle = constrain(angle, 0, 180);
  uint16_t pulse = map(angle, 0, 180, SERVOMIN, SERVOMAX);
  pwm.setPWM(pcaChannel, 0, pulse);
}

void setServoAngle(uint8_t servoId, int angle) {
  if (servoId < 1 || servoId > 4) return;

  angle = (servoId == 4) ? constrain(angle, SERVO_S4_MIN, SERVO_S4_MAX)
                         : constrain(angle, 0, 180);
  int actualAngle = angle;
  if (servoId == 4) {
    armServoAngle = angle;
  } else if (servoId == 1) {
    panAngle = angle;
  }

  setServoRawChannel(SERVO_CH[servoId - 1], actualAngle);
}

void setGripperAngle(int angle) {
  gripperAngle = constrain(angle, 0, 180);
  setServoAngle(2, gripperAngle);
#if GRIPPER_S3_REVERSED
  setServoAngle(3, 180 - gripperAngle);
#else
  setServoAngle(3, gripperAngle);
#endif
}

void setGripperState(uint8_t state) {
  setGripperStateFast(state);
}

void setGripperStateFast(uint8_t state) {
  gripperState = (state == GRIPPER_STATE_CLOSED) ? GRIPPER_STATE_CLOSED : GRIPPER_STATE_OPEN;
  gripperTargetAngle = (gripperState == GRIPPER_STATE_OPEN) ? GRIPPER_OPEN_ANGLE : GRIPPER_CLOSE_ANGLE;
  setGripperAngle(gripperTargetAngle);
  Serial.printf("GRIPPER: %s fast angle=%d\n",
                gripperState == GRIPPER_STATE_OPEN ? "open" : "close",
                gripperAngle);
}

void setGripperReleaseAngleFast(int angle) {
  gripperState = GRIPPER_STATE_OPEN;
  gripperTargetAngle = constrain(angle, 0, 180);
  setGripperAngle(gripperTargetAngle);
  Serial.printf("GRIPPER: release angle=%d\n", gripperAngle);
}

void updateLaserForMode() {
  const uint32_t now = millis();
  if (laserRcConnectBlinkActive) {
    if (now - laserRcConnectBlinkStartMs < LASER_RC_CONNECTED_BLINK_DURATION_MS) {
      if (now - lastLaserBlinkMs >= LASER_RC_CONNECTED_BLINK_INTERVAL_MS) {
        lastLaserBlinkMs = now;
        laserBlinkState = !laserBlinkState;
        digitalWrite(LASER_PIN, laserBlinkState ? HIGH : LOW);
      }
      return;
    }
    laserRcConnectBlinkActive = false;
  }

  const int ch5 = channel(RC_CH5_INDEX);
  const int ch6 = channel(RC_CH6_INDEX);
  const bool autoMode = ch5 >= RC_OUT_MID && ch6 >= RC_OUT_MID;
  const uint32_t blinkIntervalMs = autoRunning ? LASER_AUTO_RUNNING_BLINK_INTERVAL_MS
                                               : LASER_BLINK_INTERVAL_MS;

  if (!autoMode) {
    laserBlinkState = true;
    digitalWrite(LASER_PIN, HIGH);
    return;
  }

  if (now - lastLaserBlinkMs >= blinkIntervalMs) {
    lastLaserBlinkMs = now;
    laserBlinkState = !laserBlinkState;
    digitalWrite(LASER_PIN, laserBlinkState ? HIGH : LOW);
  }
}

void startLaserRcConnectBlink() {
  laserRcConnectBlinkStartMs = millis();
  laserRcConnectBlinkActive = true;
  lastLaserBlinkMs = 0;
  laserBlinkState = false;
  Serial.println("RC connected: laser fast blink for 3 seconds");
}

void handleFailsafe() {
  if (!failsafeTriggered) {
    digitalWrite(LASER_PIN, HIGH);
    emergencyStopAllMotors();
    cancelAutoMacro(false);
    failsafeTriggered = true;
    Serial.println("FAILSAFE TRIGGERED");
  }
}

bool handleFailsafeAndRecovery() {
  if (!failsafeTriggered) return true;

  if (allSticksCentered()) {
    failsafeTriggered = false;
    Serial.println("FAILSAFE CLEARED");
    return true;
  }

  return false;
}

void handleDriveMode() {
  int vx = channelPercent(channel(RC_CH1_INDEX)) * CHASSIS_X_SIGN;
  int vy = channelPercent(channel(RC_CH2_INDEX)) * CHASSIS_Y_SIGN;
  int w = channelPercent(channel(RC_CH4_INDEX)) * CHASSIS_W_SIGN;

  int m[4] = {
      (vy - vx + w) * M1_SIGN,
      (-vy + vx + w) * M2_SIGN,
      (-vy - vx + w) * M3_SIGN,
      (vy + vx + w) * M4_SIGN
  };

  int maxAbs = 1;
  for (uint8_t i = 0; i < 4; i++) {
    maxAbs = max(maxAbs, abs(m[i]));
  }
  if (maxAbs > WHEEL_CMD_MAX) {
    for (uint8_t i = 0; i < 4; i++) {
      m[i] = (long)m[i] * WHEEL_CMD_MAX / maxAbs;
    }
  }

  for (uint8_t i = 0; i < 4; i++) {
    setMotorSpeed(i, m[i]);
  }
}

void handleTrayMode() {
  stopChassisOnce();

  if (trayCh1Edge.low(channel(RC_CH1_INDEX))) {
    setMotorAbsPosition(5, motor6Pos - M6_STEP);
    Serial.printf("M6 tray left -> %ld\n", (long)motor6Pos);
  }
  if (trayCh1Edge.high(channel(RC_CH1_INDEX))) {
    setMotorAbsPosition(5, motor6Pos + M6_STEP);
    Serial.printf("M6 tray right -> %ld\n", (long)motor6Pos);
  }
  if (trayCh2Edge.low(channel(RC_CH2_INDEX))) {
    setMotorAbsPosition(5, M6_CENTER);
    Serial.printf("M6 tray center -> %ld\n", (long)motor6Pos);
  }
}

void handleChassisFineMode() {
  int vx = channelPercentWithMax(channel(RC_CH1_INDEX), FINE_WHEEL_CMD_MAX) * CHASSIS_X_SIGN;
  int vy = channelPercentWithMax(channel(RC_CH2_INDEX), FINE_WHEEL_CMD_MAX) * CHASSIS_Y_SIGN;
  int w = channelPercentWithMax(channel(RC_CH4_INDEX), FINE_WHEEL_CMD_MAX) * CHASSIS_W_SIGN;

  int m[4] = {
      (vy - vx + w) * M1_SIGN,
      (-vy + vx + w) * M2_SIGN,
      (-vy - vx + w) * M3_SIGN,
      (vy + vx + w) * M4_SIGN
  };

  int maxAbs = 1;
  for (uint8_t i = 0; i < 4; i++) {
    maxAbs = max(maxAbs, abs(m[i]));
  }
  if (maxAbs > FINE_WHEEL_CMD_MAX) {
    for (uint8_t i = 0; i < 4; i++) {
      m[i] = (long)m[i] * FINE_WHEEL_CMD_MAX / maxAbs;
    }
  }

  for (uint8_t i = 0; i < 4; i++) {
    setMotorSpeed(i, m[i]);
  }
}

void handleGripperByChannel(int ch4) {
  if (gripperCh4Edge.low(ch4)) {
    setGripperStateFast(GRIPPER_STATE_CLOSED);
  } else if (gripperCh4Edge.high(ch4)) {
    setGripperStateFast(GRIPPER_STATE_OPEN);
  }
}

void handleArmAutoMode() {
  stopChassisOnce();
  handleGripperByChannel(channel(RC_CH4_INDEX));

  if (autoCh3Edge.high(channel(RC_CH3_INDEX), AUTO_CH3_TOP_THRESHOLD)) {
    Serial.printf("AUTO_STEP: CH3 top -> move M5 to top pos %ld\n", (long)M5_TOP_MOTOR5);
    setMotorAbsPosition(4, M5_TOP_MOTOR5, POSITION_SPEED_M5_AUTO);
    return;
  }

  if (autoCh1Edge.low(channel(RC_CH1_INDEX))) {
    startAutoState(1);
  } else if (autoCh2Edge.high(channel(RC_CH2_INDEX))) {
    startAutoState(2);
  } else if (autoCh1Edge.high(channel(RC_CH1_INDEX))) {
    startAutoState(3);
  }
}

void startAutoState(uint8_t state) {
  if (state < 1 || state > AUTO_STATE_CH2_LOW) return;

  targetAutoState = state;
  int targetS1 = 0;
  int targetS4 = 0;
  getAutoTargets(targetAutoState, autoTargetM5, targetS1, targetS4);
  const bool useHigh = transitionUsesHighPos(currentAutoState, targetAutoState);

  autoRunning = true;
  autoNeedsFinalMove = useHigh;
  autoStartM5 = motor5Pos;
  autoIntermediateM5 = (targetAutoState == AUTO_STATE_CH2_LOW) ? CH2_LOW_AUTO_LIFT_MOTOR5 : HIGH_POS;
  autoPhaseStartMs = millis();

  Serial.printf("AUTO: start state %u -> state %u\n", currentAutoState, targetAutoState);

  if (targetAutoState == 2) {
    Serial.printf("AUTO_STEP: move M5 to pickup pos %ld\n", (long)PICKUP_MOTOR5);
    setMotorAbsPosition(4, PICKUP_MOTOR5, POSITION_SPEED_M5_AUTO);
    autoPhase = AutoPhase::TurntableMovePickup;
    autoPhaseDurationMs = TURNTABLE_PICKUP_MOVE_WAIT_MS;
    return;
  }

  if (targetAutoState == 3) {
    Serial.printf("AUTO_STEP: move M5 to top pos %ld\n", (long)M5_TOP_MOTOR5);
    setMotorAbsPosition(4, M5_TOP_MOTOR5, POSITION_SPEED_M5_AUTO);
    autoPhase = AutoPhase::PreDropMoveTopForOpen;
    autoPhaseDurationMs = estimateMotor5MoveTime(autoStartM5, M5_TOP_MOTOR5);
    return;
  }

  if (useHigh) {
    Serial.printf("AUTO_STEP: move M5 to lift pos %ld\n", (long)autoIntermediateM5);
    setMotorAbsPosition(4, autoIntermediateM5, POSITION_SPEED_M5_AUTO);
    autoPhase = AutoPhase::MoveHigh;
    autoPhaseDurationMs = estimateMotor5MoveTime(autoStartM5, autoIntermediateM5);
  } else {
    Serial.println("AUTO_STEP: move M5 to target");
    setMotorAbsPosition(4, autoTargetM5, POSITION_SPEED_M5_AUTO);
    autoPhase = AutoPhase::MoveTarget;
    autoPhaseDurationMs = estimateMotor5MoveTime(autoStartM5, autoTargetM5);
  }
}

void cancelAutoMacro(bool stopMotors) {
  autoRunning = false;
  autoPhase = AutoPhase::Idle;
  if (stopMotors) {
    motorStop(4);
    motorStop(5);
  }
}
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

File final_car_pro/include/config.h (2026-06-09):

#pragma once

#include <Arduino.h>

// ==================== 旧 ESP32Robot.ino 继承引脚 ====================

// RS485 接收引脚，ESP32-S3 GPIO16 连接 TTL-RS485 模块的 RX/RO 相关信号。
#define RS485_RX_PIN 16

// RS485 发送引脚，ESP32-S3 GPIO17 连接 TTL-RS485 模块的 TX/DI 相关信号。
#define RS485_TX_PIN 17

// PCA9685 I2C 数据线 SDA，必须使用旧项目规定的 GPIO11。
#define PCA9685_SDA_PIN 11

// PCA9685 I2C 时钟线 SCL，必须使用旧项目规定的 GPIO12。
#define PCA9685_SCL_PIN 12

// 激光模块控制引脚，默认常亮；B2 自动工位模式下闪烁。
#define LASER_PIN 15

// B2 自动工位模式下激光闪烁间隔，单位毫秒。
constexpr uint32_t LASER_BLINK_INTERVAL_MS = 250;

// Laser blink interval while an automatic station action is running.
constexpr uint32_t LASER_AUTO_RUNNING_BLINK_INTERVAL_MS = 80;
constexpr uint32_t LASER_RC_CONNECTED_BLINK_INTERVAL_MS = 80;
constexpr uint32_t LASER_RC_CONNECTED_BLINK_DURATION_MS = 3000;

// Chassis drive limits used by M1-M4 wheel speed commands.
constexpr int CHASSIS_MAX_SPEED_RPM_LIMIT = 200;
constexpr uint8_t CHASSIS_ACCEL_WHEEL_LIMIT = 188;

// S4 actual-angle targets used after M5 reaches the lift/top position in auto station mode.
constexpr int AUTO_PRE_CLAMP_S4_AFTER_LIFT = 80;
constexpr int AUTO_TURNTABLE_S4_AFTER_LIFT = 170;
constexpr int AUTO_PRE_DROP_S4_AFTER_LIFT = 80;

// ==================== MC7RE / SBUS 遥控器输入 ====================

// 遥控接收机串口输入引脚，MC7RE 的 M.BUS/SBUS 信号线接 GPIO18。
#define RC_RX_PIN 18

// 遥控接收机串口发送引脚，本项目只读取接收机，GPIO19 预留不用也可以。
#define RC_TX_PIN 19

// SBUS 常见为反相信号：1 表示按反相串口读取，0 表示普通串口读取。
#define RC_SERIAL_INVERTED 1

// SBUS/M.BUS 串口波特率，标准 SBUS 通常为 100000。
#define RC_BAUD_RATE 100000

// SBUS 串口格式，标准 SBUS 通常为 8 数据位、偶校验、2 停止位。
#define RC_SERIAL_CONFIG SERIAL_8E2

// ==================== 遥控器通道索引 ====================

// CH1 在 SBUS 通道数组中的索引，默认 0；通常对应右摇杆左右。
#define RC_CH1_INDEX 0

// CH2 在 SBUS 通道数组中的索引，默认 1；通常对应右摇杆上下。
#define RC_CH2_INDEX 1

// CH3 在 SBUS 通道数组中的索引，默认 2；通常对应左摇杆上下。
#define RC_CH3_INDEX 2

// CH4 在 SBUS 通道数组中的索引，默认 3；通常对应左摇杆左右。
#define RC_CH4_INDEX 3

// CH5 在 SBUS 通道数组中的索引，默认 4；用于 A/B 大模式切换。
#define RC_CH5_INDEX 4

// CH6 在 SBUS 通道数组中的索引，默认 5；用于普通/特殊子模式切换。
#define RC_CH6_INDEX 5

// ==================== 遥控器数值范围与失控判断 ====================

// SBUS 原始最小值，标准常见范围约为 172~1811。
constexpr int RC_RAW_MIN = 172;

// SBUS 原始最大值，标准常见范围约为 172~1811。
constexpr int RC_RAW_MAX = 1811;

// 归一化后的遥控通道最小值，对应摇杆或开关一端。
constexpr int RC_OUT_MIN = 1000;

// 归一化后的遥控通道中位值，模式判断也以 1500 为分界。
constexpr int RC_OUT_MID = 1500;

// 归一化后的遥控通道最大值，对应摇杆或开关另一端。
constexpr int RC_OUT_MAX = 2000;

// 摇杆死区，通道值距离 1500 小于等于该值时视为 0；死区外按遥控器返回值线性换算速度百分比。
constexpr int RC_DEADZONE = 60;

// 遥控器超时时间，超过该毫秒数没有有效 SBUS 帧就触发 failsafe。
constexpr uint32_t RC_TIMEOUT_MS = 300;

// ==================== 底盘速度与轮电机参数 ====================

// 底盘上层速度命令最大百分比，遥控器返回值会线性映射到 -100~100。
constexpr int WHEEL_CMD_MAX = 100;

// B1 底盘微调模式的最大速度命令。
// 普通底盘模式满摇杆为 100；B1 满摇杆只到该值，实现“大行程、小速度”微调。
// 如果 B1 仍然太快，减小该值；如果车完全不动，确认它大于 MIN_EFFECTIVE_CMD。
constexpr int FINE_WHEEL_CMD_MAX = 12;

// M1~M4 轮电机最大转速，速度百分比会线性映射到 0~MAX_SPEED_RPM。
constexpr int MAX_SPEED_RPM = 250;

// 最小有效速度命令，绝对值小于该值时强制当作 0，避免低速抖动。
constexpr int MIN_EFFECTIVE_CMD = 3;

// M1~M4 轮电机速度模式加速度参数，继承旧项目设置。


constexpr uint8_t ACCEL_WHEEL = 250;

// 底盘横移方向修正：1 保持当前方向，-1 反转 CH1 横移方向。
#define CHASSIS_X_SIGN -1

// 底盘前后方向修正：1 保持当前方向，-1 反转 CH2 前后方向。
#define CHASSIS_Y_SIGN 1

// 底盘原地转向方向修正：1 保持当前方向，-1 反转 CH4 转向方向。
#define CHASSIS_W_SIGN -1

// M1 单轮方向修正：1 保持当前方向，-1 反转 M1。
#define M1_SIGN 1

// M2 单轮方向修正：1 保持当前方向，-1 反转 M2。
#define M2_SIGN 1

// M3 单轮方向修正：1 保持当前方向，-1 反转 M3。
#define M3_SIGN 1

// M4 单轮方向修正：1 保持当前方向，-1 反转 M4。
#define M4_SIGN 1

// ==================== M5 / M6 绝对位置模式参数 ====================

// M5 机械臂升降电机的位置模式加速度参数，继承旧项目设置。
constexpr uint8_t ACCEL_MOTOR5 = 250;

// M6 物料盘旋转电机的位置模式加速度参数，继承旧项目设置。
constexpr uint8_t ACCEL_MOTOR6 = 40;

// M5 默认位置命令速度参数；自动工位会显式使用 POSITION_SPEED_M5_AUTO。
constexpr uint16_t POSITION_SPEED_M5 = 1000;

// M5 自动工位时使用的运动速度参数，只影响 B2 自动工位模式。
// 如果自动工位中 M5 太快，就调小这个值；如果太慢，就调大这个值。
constexpr uint16_t POSITION_SPEED_M5_AUTO = 2000;

// M6 绝对位置命令使用的运动速度参数，只影响物料盘电机。
constexpr uint16_t POSITION_SPEED_M6 = 60;

// 位置命令模式字节，0x01 表示绝对位置模式。
constexpr uint8_t POSITION_MODE_ABSOLUTE = 0x01;

// 位置命令同步字节，0x00 表示不启用多机同步。
constexpr uint8_t POSITION_SYNC_DISABLED = 0x00;

// M5 机械臂升降最小目标脉冲数；现在 motor5Pos 直接就是发给电机的位置脉冲。
constexpr int32_t M5_PULSE_MIN = 0;

// M5 机械臂升降最大目标脉冲数；程序会把 M5 限制在 M5_PULSE_MIN~M5_PULSE_MAX。
constexpr int32_t M5_PULSE_MAX = 158000;




// M5 每次手动升降增加或减少的脉冲数，CH3 持续打到底时每 50ms 改一次。
constexpr int32_t M5_STEP = 1000;

// M5 方向修正：1 保持当前 CH3 上推位置减小，-1 反转升降方向。
#define M5_DIR_SIGN 1

// M6 物料盘最小目标脉冲数，负数表示一个方向旋转。
constexpr int32_t M6_MIN = -100000;

// M6 物料盘最大目标脉冲数，正数表示另一个方向旋转。
constexpr int32_t M6_MAX = 100000;

// M6 物料盘回中目标脉冲数；现在不再换算角度，直接作为脉冲目标发送。
constexpr int32_t M6_CENTER = 1800;

// M6 每次左右转动增加或减少的脉冲数。
constexpr int32_t M6_STEP = 533;

// 转台连贯宏中 M6 每次自动转盘步进脉冲数；方向反了可改成 -M6_STEP。
constexpr int32_t AUTO_TURNTABLE_M6_STEP = M6_STEP;

// ==================== PCA9685 与舵机参数 ====================
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

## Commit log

2026-05-30 robotarm car control project
    [100mmMGN7滑轨.SLDPRT, 150mm5mm光轴.SLDPRT, 1650电池.SLDPRT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]
2026-07-09 Add README for ESP32-S3 remote control car project
    Added detailed documentation for ESP32-S3 remote control car project, including wiring diagrams, control parameters, debugging steps, and troubleshooting tips.
